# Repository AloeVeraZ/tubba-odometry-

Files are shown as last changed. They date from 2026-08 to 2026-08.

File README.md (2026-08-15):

<div align="center">

# Tubba Odometry

### A compact spring-loaded dead-wheel odometry tracking pod for FTC robotics







<picture>
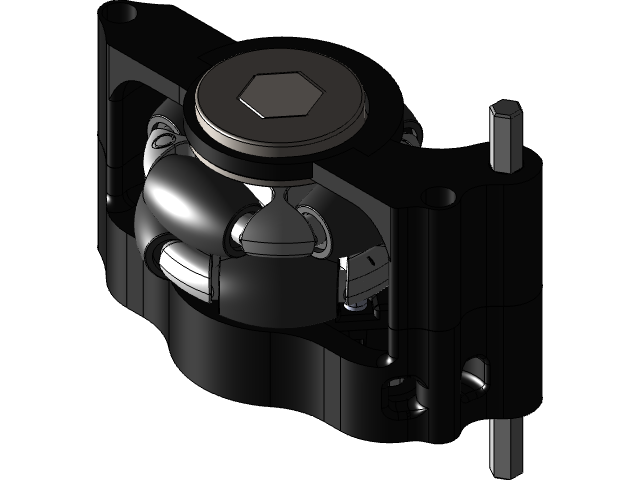
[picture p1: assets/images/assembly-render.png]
Tubba Odometry assembly render
  
</picture>

A high-accuracy, passive dead-wheel odometry module engineered with AndyMark Dualie omni wheels and REV Through Bore Encoders for real-time planar localization.

<strong>Quick navigation:</strong><br>
[Module Overview](#what-is-tubba) | [Bill of Materials](#bill-of-materials) | [CAD Files](cad/) | [Gallery](#gallery) | [GrabCAD Model](https://grabcad.com/library/tubba-odometry-for-ftc-1)

</div>

---

## What is Tubba?

**Tubba** is a compact dead-wheel odometry pod engineered by FTC Team 9384 Hydraulic Hydras. It provides a passive, unpowered omni tracking wheel in continuous ground contact, measuring independent translational and rotational displacement for dead reckoning and localization libraries such as Road Runner.

The assembly is built around an AndyMark **2 in. Dualie Omni Wheel** (1/2" hex, 50A durometer) paired with a **REV Through Bore Optical Encoder**. It was designed to package compactly between the parallel structural plates of Team 9384's 2023–2024 robot, **EggWUUUHH**.

| Subsystem Specification | Technical Details |
| --- | --- |
| Tracking wheel | AndyMark 2 in. Dualie Omni Wheel (50A durometer for low lateral scrub) |
| Encoder type | REV Through Bore Optical Shaft Encoder (8192 counts/rev in quadrature) |
| Suspension & preload | Surgical tubing / spring tensioned pivot for continuous floor compliance |
| Mounting architecture | Direct plate mounting with integrated flanged hex bearings |
| Hardware standard | M3 socket head cap screws + hex nuts |

> [!NOTE]
> The STEP solid model serves as the dimensional source of truth. Validate your 3D printer slicing tolerances, bearing press-fits, and robot frame clearances before volume manufacturing.

## Gallery

<div align="center">

| Physical Assembled Prototype | Master CAD Solid Assembly |
| :---: | :---: |
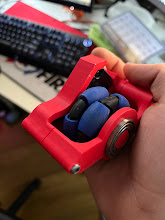
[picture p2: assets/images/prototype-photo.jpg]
Tubba Odometry prototype
|  | Complete Tubba Odometry CAD assembly |

</div>

<div align="center">

| Sensor Side Plate CAD | Outer Retaining Plate CAD |
| :---: | :---: |
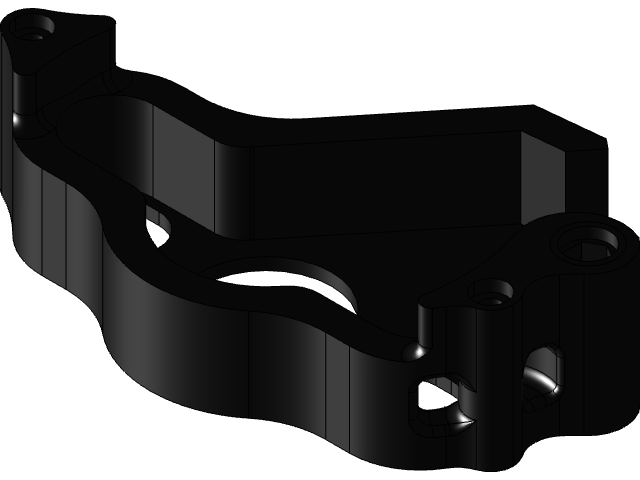
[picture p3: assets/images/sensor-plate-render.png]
Sensor plate CAD render
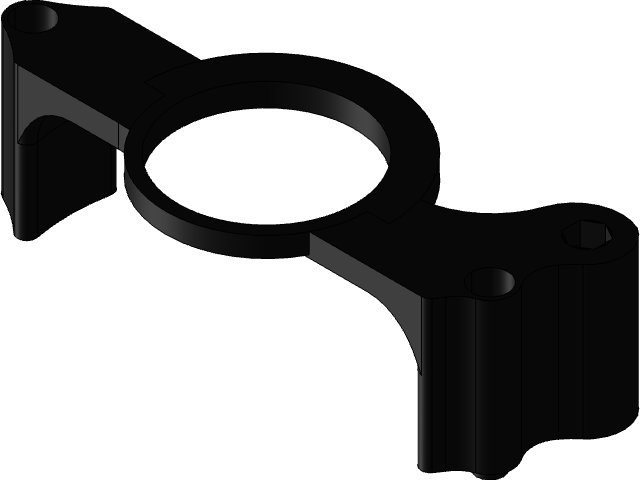
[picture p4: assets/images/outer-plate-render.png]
Outer plate CAD render
|  |  |

</div>

## Bill of Materials

Sourcing list for **one odometry module** (mirrors the original Team 9384 BOM):

| Item | Component Description | Supplier / Source | Part Number | Qty. | Direct Link |
| :---: | --- | --- | --- | :---: | :---: |
| 1 | 3D-Printed Structural Plates | 3D Printed (PETG/PLA) | `cad/` | 1 set | [View Models](cad/) |
| 2 | Optical Through Bore Encoder | REV Robotics | REV-11-1271 | 1 | [REV Store](https://www.revrobotics.com/rev-11-1271/) |
| 3 | 2" Dualie Omni Wheel (1/2" Hex, 50A) | AndyMark | am-4684_50A | 1 | [AndyMark Store](https://www.andymark.com/products/2-in-dualie-omni-wheel) |
| 4 | 1/2" Hex Flanged Bearing (FR8ZZ-HexHD) | AndyMark | FR8ZZ-HexHD | 1 | [AndyMark Store](https://www.andymark.com/products/0-5-in-hex-id-1-125-in-od-shielded-flanged-bearing-fr8zz-hexhd) |
| 5 | 5 mm Hex Shaft Stock | REV Robotics | REV-41-1362-PK4 | 1 | [REV Store](https://www.revrobotics.com/5mm-Hex-Shafts/) |
| 6 | 3 mm ID Preload Surgical Tubing | REV Robotics | REV-41-1163 | 1 | [REV Store](https://www.revrobotics.com/rev-41-1163/) |
| 7 | M3 × 45 mm Socket Head Screws | Fastener Supply | — | 1 pack | [Amazon](https://www.amazon.com/dp/B0967ZTRXB) |
| 8 | M3 Nylon-Insert Lock Nuts | Fastener Supply | — | 1 pack | [Amazon](https://www.amazon.com/dp/B0CR3S4MZT) |

Portable tabular BOM data is preserved in [`docs/BOM.csv`](docs/BOM.csv) and [Google Sheets](https://docs.google.com/spreadsheets/d/17jjdt58DgWxnq1DswMJ4VjZQLS4xurBlHhdxET_VKbg/edit?usp=sharing).

## CAD Collection

Neutral ISO 10303 STEP exports in [`cad/`](cad/):
- [`cad/9384 odom final v1.step`](cad/9384%20odom%20final%20v1.step): Master assembled module
- [`cad/sensor plate.step`](cad/sensor%20plate.step): Inner encoder mounting plate
- [`cad/outter plate.step`](cad/outter%20plate.step): Outer bearing retaining plate
- [`cad/hex shaft mod.step`](cad/hex%20shaft%20mod.step): Machined hex shaft profile

## License & Attribution

Original design, models, and documentation © 2024–2026 **Angelo Demetroulakos**. Licensed under the **[Creative Commons Attribution 4.0 International License](LICENSE)**.

```text
Based on Tubba Odometry for FTC by Angelo Demetroulakos and FTC Team 9384 Hydraulic Hydras,
licensed under CC BY 4.0. Source: https://grabcad.com/library/tubba-odometry-for-ftc-1
```

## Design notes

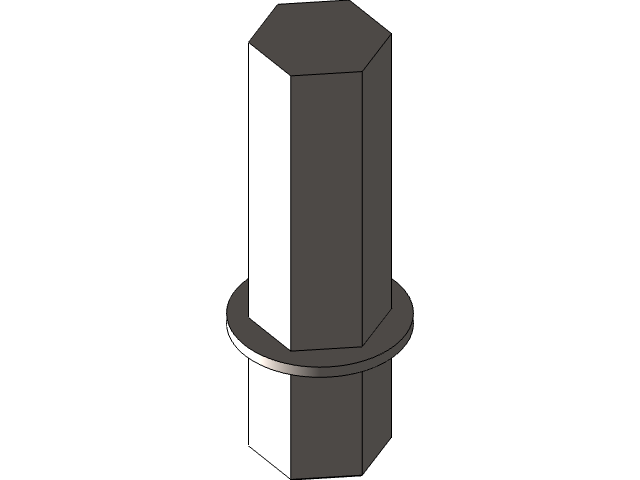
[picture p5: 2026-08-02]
assets/images/hex-shaft-render.png

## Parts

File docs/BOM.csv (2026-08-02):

FTC Team 9384 Tubba Odometry Bill of Materials (BOM) Per Module
Item # | Description | Vendor | Part Number | Qty | Cost | Link to Purchase
1 | 3D printed parts | GrabCAD | N/A | 1 per part | N/A | N/A
2 | Through Bore Encoder | REV Robotics | REV-11-1271 | 1 | $48.00 | https://www.revrobotics.com/rev-11-1271/
3 | 2 in. Dualie Omni Wheel (1/2 Hex, 50A) | Andy Mark | N/A | 1 | $15.50 | https://www.andymark.com/products/2-in-dualie-omni-wheel?Bore=1%2F2+Hex&Durometer=50A
4 | 1/2 Hex ID 1.125in. OD shielded flanged bearing | Andy Mark | FR8ZZ-HexHD | 1 | $6.50 | https://www.andymark.com/products/0-5-in-hex-id-1-125-in-od-shielded-flanged-bearing-fr8zz-hexhd
5 | 5mm hex shaft | REV Robotics | REV-41-1362-PK4 | 1 | $11.50 - $21.50 | https://www.revrobotics.com/5mm-Hex-Shafts/
6 | 3mm surgical tubing | REV Robotics | REV-41-1163 | 1 | $7.00 | https://www.revrobotics.com/rev-41-1163/
7 | M3 x 45mm bolts | Amazon | N/A | 1 | $8.99 | https://www.amazon.com/Socket-Screws-Metric-Machine-Threaded/dp/B0967ZTRXB?hvadid=675657104776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
8 | M3 nuts | Amazon | N/A | 1 | $8.99 | https://www.amazon.com/Mriuuod-Hex-M3-Nuts-Replacement/dp/B0CR3S4MZT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

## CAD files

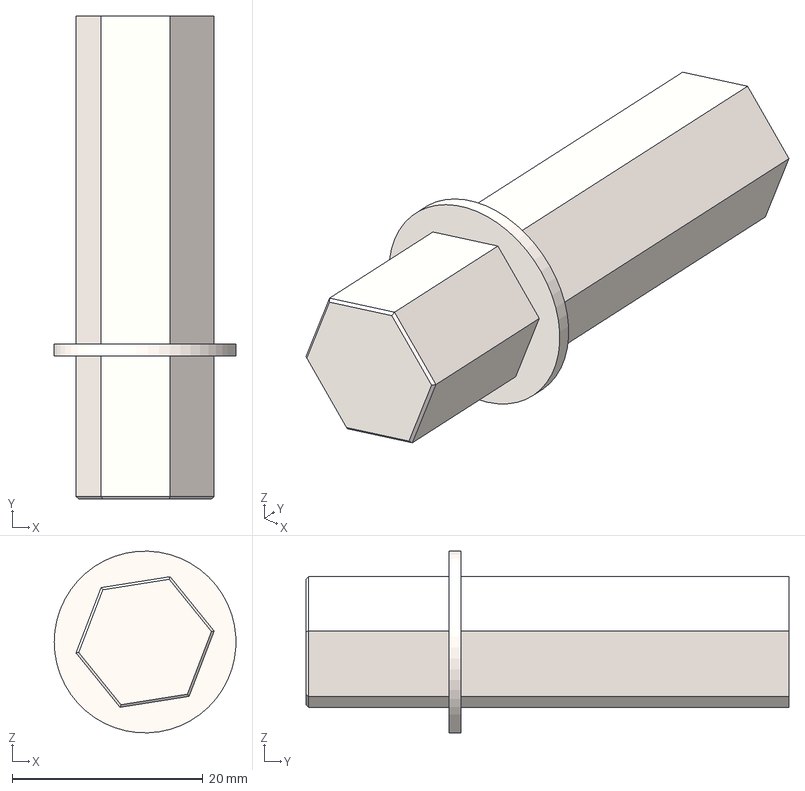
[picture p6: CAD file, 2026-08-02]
cad/hex shaft mod.step
19.0 x 50.6 x 19.0 mm

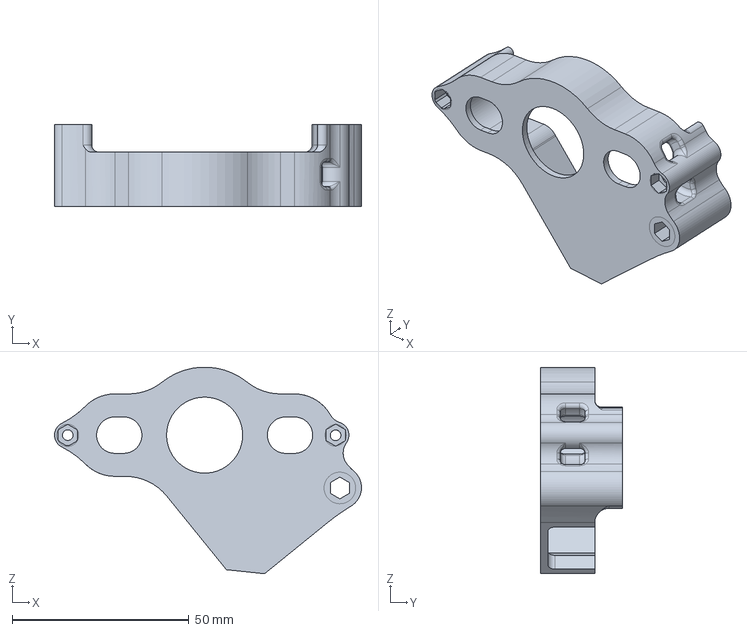
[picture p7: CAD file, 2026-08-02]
cad/sensor plate.step
86.8 x 23.1 x 58.4 mm

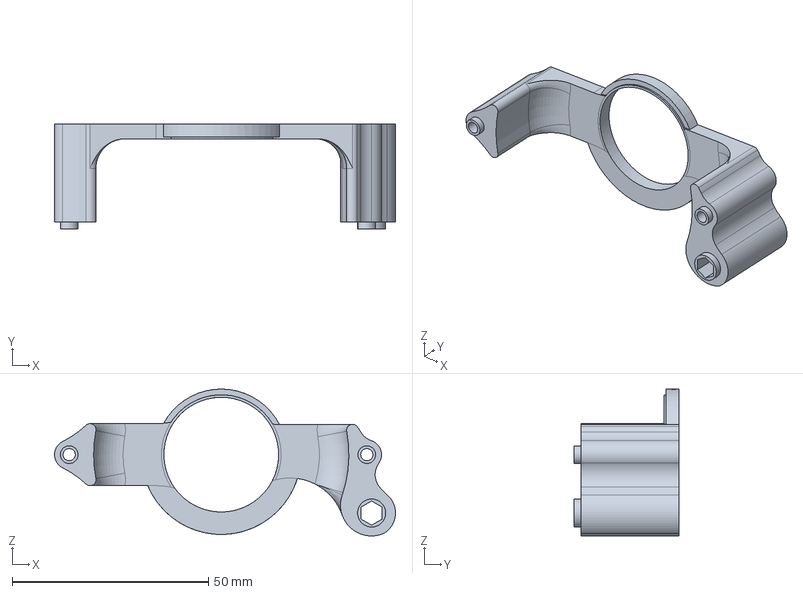
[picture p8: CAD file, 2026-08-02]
cad/outter plate.step
86.8 x 26.8 x 37.4 mm

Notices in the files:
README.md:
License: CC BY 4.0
